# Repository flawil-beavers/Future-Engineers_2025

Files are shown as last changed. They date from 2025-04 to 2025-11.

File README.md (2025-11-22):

# Flawil Beavers

## Future-Engineers_2025

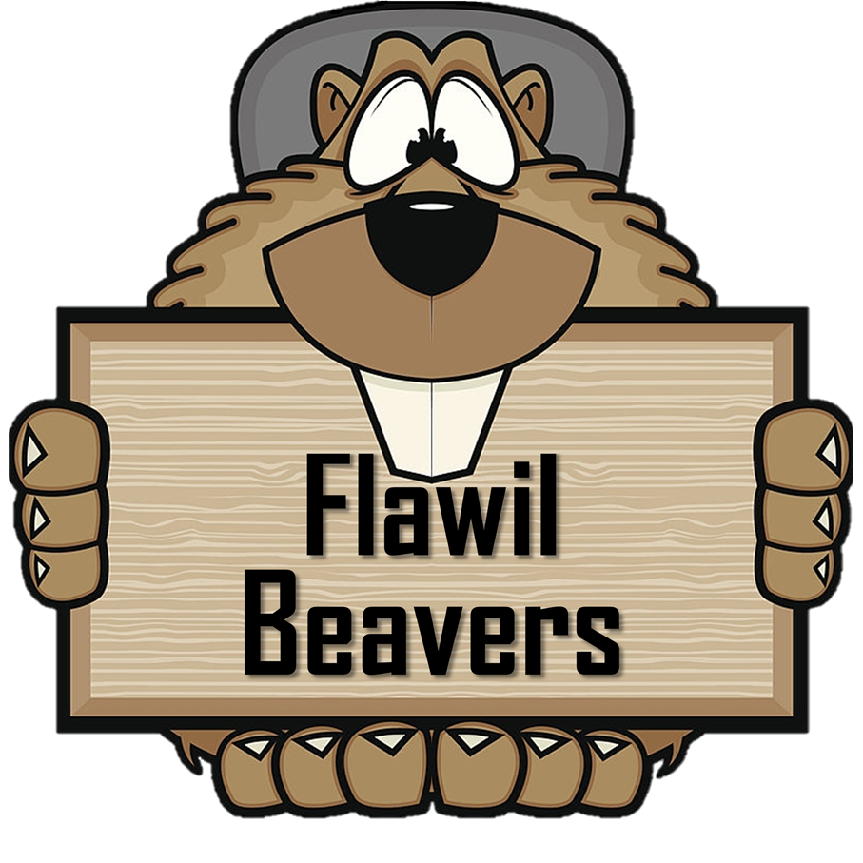
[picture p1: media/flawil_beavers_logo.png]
Flawil Beavers Logo


| Opening Challenge | Obstacle Challenge |
|---|---|
| Watch the Opening Race (https://youtu.be/OofLgNROook) | Watch the Obstacle Race (https://youtu.be/P_mGKfEbACU) |
|  |  |

**This is the GitHub repository for team Flawil Beavers for WRO 2025. You'll find our documentation in this README.**

---

## Contents

- [Introduction](#introduction)

- [Mobility Management](#mobility-management)
  - [Assembly Instructions](#assembly-instructions)
  - [Structural and Mechanical Design](#structural-and-mechanical-design)

- [Power and Sense Management](#power-and-sense-management)  
  - [Power Management](#power-management)  
  - [Sense Management](#sense-management)
  - [Wiring Diagram and Bill of Materials](#wiring-diagram-and-bill-of-materials)
    - [Wiring Diagram](#wiring-diagram)
    - [Bill of Materials](#bill-of-materials)

- [Obstacle Management](#obstacle-management)  
  - [Software Architecture](#software-architecture)  
  - [Opening Race](#opening-race)  
  - [Obstacle Race](#obstacle-race)  
    - [Colour Detection](#colour-detection)  
    - [Wall Following](#wall-following)
  - [Firmware Running on the Arduino](#firmware-running-on-the-arduino)  
    - [Overview of custom Firmware Operation](#overview-of-custom-firmware-operation)  
    - [System-Level Interaction Diagram](#system-level-interaction-diagram)

- [Own platform for Streams](#own-platform-for-streams)

- [Photos](#photos)  
- [Videos](#videos)

- [Enabling Reproducibility](#enabling-reproducibility)

- [Future Improvements](#future-improvements)

---

## Introduction

We, **Damian Hardegger** and **Philipp Kündig**, form the WRO team **Flawil Beavers**. Since 2019, we have been actively participating in the World Robot Olympiad, starting in the RoboMission category where we achieved several successful results. In 2024, we decided to take on a new challenge and moved into the Future Engineers category. There, we gained our first experience with autonomous driving and vehicle robotics — and even managed to win the Open Championships in Italy.

This documentation provides a complete technical overview of our Future Engineers project, including the mechanical design, electronics, software architecture, and our development process. The goal of this README is to offer a clear reference for judges, mentors, and other teams who may benefit from our approach, CAD files, wiring diagrams, and assembly instructions.

We believe in transparent engineering and hope that sharing our work contributes to the WRO community and inspires teams entering the Future Engineers category.

---

## Mobility Management

### Assembly Instructions

Below you’ll find a concise assembly guide covering all major build steps.

---

<details><summary><span style="font-size:1.4em; font-weight:700;">Step 1 – Preparations</span></summary>

Gather all required materials according to the [**Bill of Materials (BOM)**](#bill-of-materials) and print all necessary **[3D‑Printed‑Parts / CAD & STL](./CAD/Seperate%20Parts/)**.  
Use **M3 screws** and **M3nS/M3n nuts** for all mechanical components, and **M2 screws** with **M2n nuts** for electronic parts.

> ⚠️ **Note:**  
> For the **base plate** and **battery cover**, **magnets must be inserted after the printing process**.  

</details>

---

<details><summary><span style="font-size:1.4em; font-weight:700;">Step 2 – Base Plate and Drive Assembly</span></summary>

Take the printed **[base plate](./CAD/Seperate%20Parts/Base.3mf)** and begin by mounting the two **motors**.  
The **drive motor** is positioned in the center and secured with the [DC motor cover](./CAD/Seperate%20Parts/DC%20motor%20cover.3mf).  
Place a **coupling** between the motor shaft and the **LEGO axle** – we recommend a **metal coupling**, though [Shaft](./CAD/Seperate%20Parts/Shaft.3mf) can also be used.

Next, install the [Gearbox back](./CAD/Seperate%20Parts/Gearbox%20back.3mf) as well as the [Gearbox front](./CAD/Seperate%20Parts/Gerbox%20front.3mf) and [Gearbox front inset](./CAD/Seperate%20Parts/Gearbox%20front%20inset.3mf) on the base plate.  
Attach the **servo motor** using [Servo shaft](./CAD/Seperate%20Parts/Servo%20shaft.3mf) + [Servo shaft lego](./CAD/Seperate%20Parts/Servo%20shaft%20lego.3mf) and ensure all fasteners are tight.

Route the **motor cables to the side**, so they remain accessible later.  
Finally, verify that **all shafts are properly aligned and firmly fastened**.

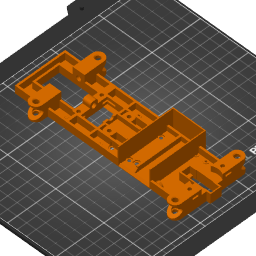
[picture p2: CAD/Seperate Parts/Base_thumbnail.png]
base plate
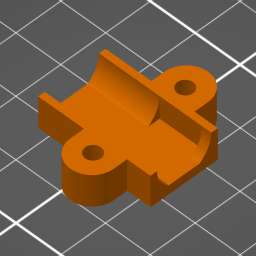
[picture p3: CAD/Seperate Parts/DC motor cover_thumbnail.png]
DC motor cover
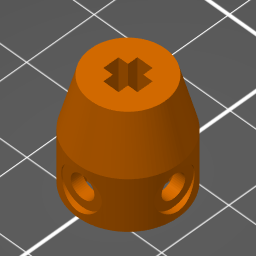
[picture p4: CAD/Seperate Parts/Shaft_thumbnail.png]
Shaft
|<br> **Base plate**|  <br> **DC motor cover** |  <br> **Shaft** |
|---|---|---|
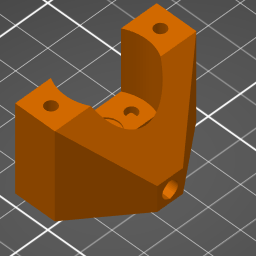
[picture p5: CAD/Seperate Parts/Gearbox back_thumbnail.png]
Gearbox back
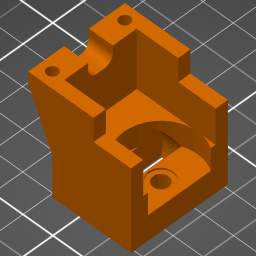
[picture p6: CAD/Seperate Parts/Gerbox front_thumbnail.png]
Gerbox front
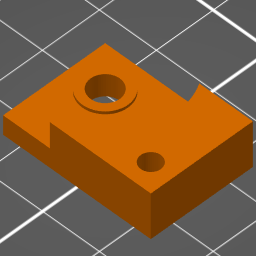
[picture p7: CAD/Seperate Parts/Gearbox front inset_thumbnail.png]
Gearbox front inset
| <br> **Gearbox back**|  <br> **Gerbox front** |  <br> **Gearbox front inset** |

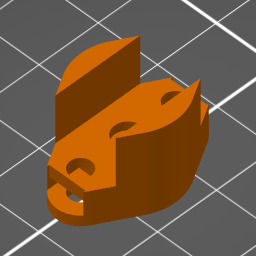
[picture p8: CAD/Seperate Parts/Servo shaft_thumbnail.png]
Servo shaft
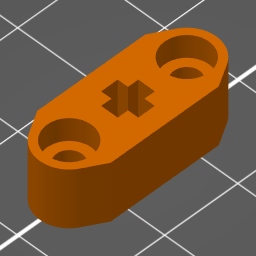
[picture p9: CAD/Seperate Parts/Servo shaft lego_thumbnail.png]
Servo shaft
 <br> **Servo shaft** | <br> **Servo shaft lego** |
|---|---|

</details>

---

<details><summary><span style="font-size:1.4em; font-weight:700;">Step 3 – LEGO Component Assembly</span></summary>

Attach the **LEGO components** to the 3D-printed parts as shown below.

**[LEGO Assembly](CAD/Lego_Chassis.io)**
<br>
<br>

<p align="center">
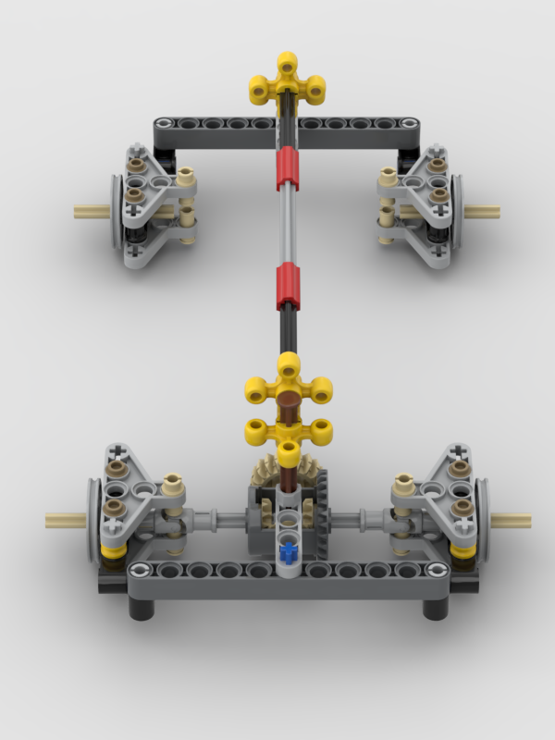
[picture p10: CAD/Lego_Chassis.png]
Lego Chassis
    
    <br>
    <strong>LEGO Chassis</strong>
</p>

Ensure all connections fit snugly and that no parts are misaligned.

</details>

---

<details><summary><span style="font-size:1.4em; font-weight:700;">Step 4 – Steering 
Axle</span></summary>

Check that you have installed both **gearboxes (step 2)** onto the base plate, then complete the **steering shaft assembly**.  
A **metal rod** is recommended; alternatively, a **16 cm LEGO steering bar** can be used.

These components secure all shafts in place and ensure stable **gear engagement**.  
Verify that all gears rotate smoothly and are properly meshed.

</details>

---

<details><summary><span style="font-size:1.4em; font-weight:700;">Step 5 – Computer Mounting Plate</span></summary>

Attach [Raspberry holder](./CAD/Seperate%20Parts/Rasbperry%20holder.3mf), the **mounting plate for the Raspberry Pi and the [cover top lower](./CAD/Seperate%20Parts/Cover%20top%20lower.3mf)**, to the supports installed in the previous step.  
Then, mount the [Camera mount](./CAD/Seperate%20Parts/Camera%20mount.3mf) on top of this plate as shown in the image.

**[Complete vehicle model](./CAD/Car%20v87.step)**

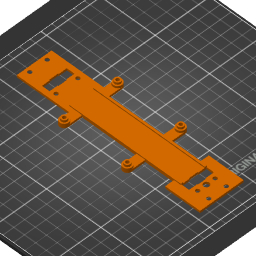
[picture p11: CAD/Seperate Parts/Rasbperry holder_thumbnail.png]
Raspberry holder
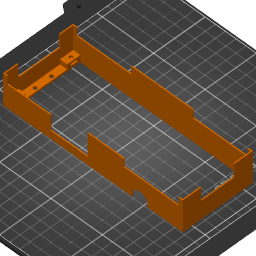
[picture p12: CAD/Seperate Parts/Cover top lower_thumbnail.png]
cover top lower
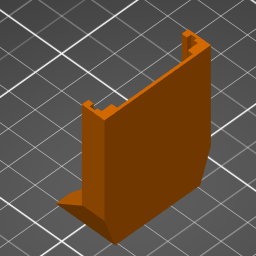
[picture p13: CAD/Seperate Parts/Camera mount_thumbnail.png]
Camera mount
|  <br> **Raspberry holder** |  <br> **cover top lower** |  <br> **Camera mount** |
|---|---|---|

<br>
Make sure the alignment is precise so that cables and connectors remain easily accessible.

</details>

---

<details><summary><span style="font-size:1.4em; font-weight:700;">Step 6 – Installing the Electronics</span></summary>

Flash the **micro SD card for the Raspberry Pi** and the **Arduino Nano** according to step 1 in **[software documentation](#enabling-reproducibility)**.

Mount the **Raspberry Pi** onto the upper plate.  
The **Arduino Nano** will be connected later and should remain **temporarily unattached** for now.

Carefully turn the robot upside down and install the remaining **electrical components** on the underside, following the reference picture.

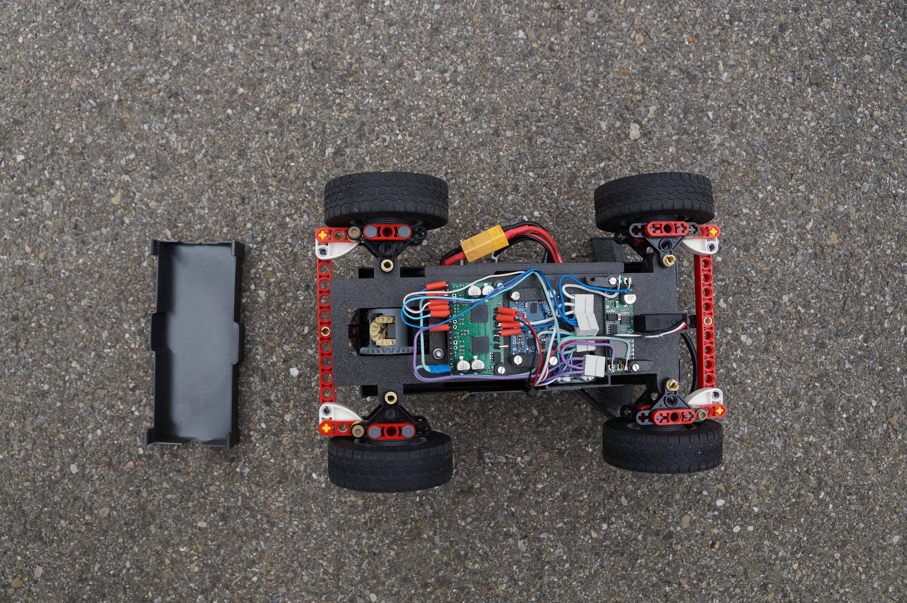
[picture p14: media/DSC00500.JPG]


Use the washers and fastening materials:

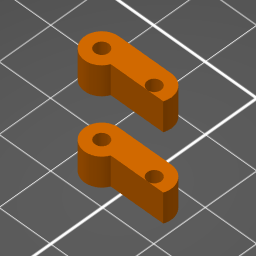
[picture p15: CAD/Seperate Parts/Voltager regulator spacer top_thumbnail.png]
Voltage regulator spacer top
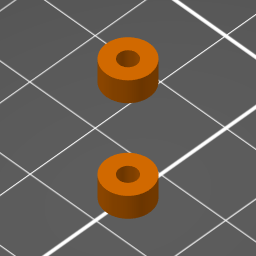
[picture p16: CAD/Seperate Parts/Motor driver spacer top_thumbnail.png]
Motor driver spacer top
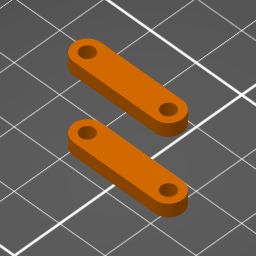
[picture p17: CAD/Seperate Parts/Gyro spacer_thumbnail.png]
Gyro spacer
|  <br> **[Voltage regulator](./CAD/Seperate%20Parts/Voltager%20regulator%20spacer%20top.3mf)**| <br> **[Motor driver](./CAD/Seperate%20Parts/Motor%20driver%20spacer%20top.3mf)** | <br> **[Gyro spacer](./CAD/Seperate%20Parts/Gyro%20spacer.3mf)**|
|---|---|---|

> 💡 **Tip:**  
> Use **nylon washers or plastic spacers** under PCBs to prevent short circuits.

</details>

---

<details><summary><span style="font-size:1.4em; font-weight:700;">Step 7 – Wiring</span></summary>

Follow the provided **[Wiring Diagram](#wiring-diagram)** to correctly interconnect all components.  
The **Arduino Nano** can temporarily remain on the top side for easy access.

Solder the wires of the power components on the underside and use **connectors** where possible to simplify maintenance.  
For the main power supply, **WAGO terminals** can be placed in the front interior compartment of the robot.

> ⚠️ **Warning:**  
> Double-check **all GND and power connections**.  
> Incorrect wiring may damage components or even cause **short circuits and fire hazards**.

</details>

---

<details><summary><span style="font-size:1.4em; font-weight:700;">Step 8 – Enclosure Assembly</span></summary>

Place [Bottom cover](./CAD/Seperate%20Parts/Bottom%20cover.3mf) over the wiring from underneath – it should **snap into place securely**.  
Then, flip the robot back upright and prepare the [top cover](./CAD/Seperate%20Parts/Cover%20top%20upper.3mf).

Mount the **toggle switches** and the **status LED** as shown, and connect them directly to the Arduino.

Before fully closing the housing:

1. Connect the **camera module** and route the ribbon cable through the opening.  
2. Link the **Arduino Nano** to the **Raspberry Pi** using a **USB-A to Micro-USB cable**.  
3. Once completed, install and fasten the housing completely.

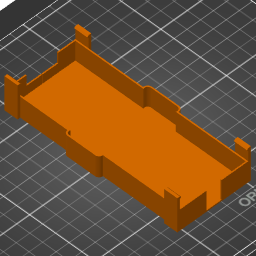
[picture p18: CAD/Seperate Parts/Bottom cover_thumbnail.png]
Bottom cover
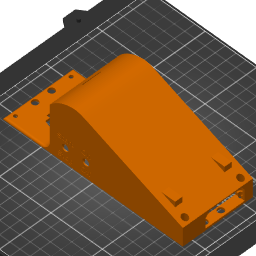
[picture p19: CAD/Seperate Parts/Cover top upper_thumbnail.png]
top cover
|  <br> **Bottom cover** |  <br> **Top cover** |
|---|---|

</details>

---

<details><summary><span style="font-size:1.4em; font-weight:700;">Step 9 – Hardware Finalization</span></summary>

Mount the **camera** at the front of the robot.  
Carefully attach the **lens**, making sure it is free of dust and properly focused.  
Tighten it fully to prevent image blur caused by vibration.

To finish:

- Install the [rear spoiler](./CAD/Seperate%20Parts/spoiler_full_2.3mf) (for that extra aerodynamic performance 😎).
- Don't forget to install the [Battery holder](./CAD/Seperate%20Parts/Battery%20holder.3mf).
- Attach the **wheels**.

Your robot’s **hardware assembly** is now complete and ready for operation.

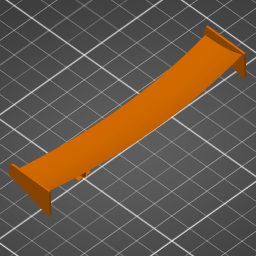
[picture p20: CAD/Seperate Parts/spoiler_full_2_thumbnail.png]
Rear spoiler
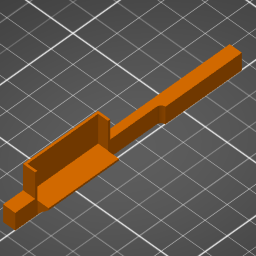
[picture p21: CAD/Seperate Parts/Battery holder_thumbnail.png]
Battery holder
|  <br> **Rear spoiler 😎** |  <br> **Battery holder** |
|---|---|

</details>

---

<details><summary><span style="font-size:1.4em; font-weight:700;">Step 10 – Software Installation and Setup</span></summary>

Carefully read through the **[software documentation](#enabling-reproducibility)** and install all required software packages on the **Raspberry Pi** and **Arduino Nano**.  
Upload the corresponding **firmware, scripts, and configuration files** as described in the software section.

> **Congratulations!**  
> Your robot is now fully assembled and ready for its first run.  
> Enjoy driving, experimenting, and improving your creation!

</details>

---

<!-- Mobility management discussion should cover how the vehicle movements are managed. What motors are selected, how they are selected and implemented.
A brief discussion regarding the vehicle chassis design /selection can be provided as well as the mounting of all components to the vehicle chassis/structure. The discussion may include engineering principles such as speed, torque, power etc. usage. Building or assembly instructions can be provided together with 3D CAD files to 3D print parts. -->

### Structural and Mechanical Design

The robot is constructed almost entirely from 3D-printed components, with the exception of axles, wheels, and gears made from Lego parts. Lego components were chosen for their flexibility and ease of replacement. To improve precision and durability, we upgraded one axle and one coupling from plastic to metal, enhancing mechanical reliability under repetitive use.

All electronic components are embedded directly into the 3D-printed structure. The robot employs a double Ackerman steering mechanism on both axles, allowing precise control and tight turning. A differential is integrated into the front axle to evenly distribute torque between the front wheels, improving stability and efficiency during motion.

A complete overview of the 3D-printed parts and how they fit together can be seen in our Fusion 360 model:

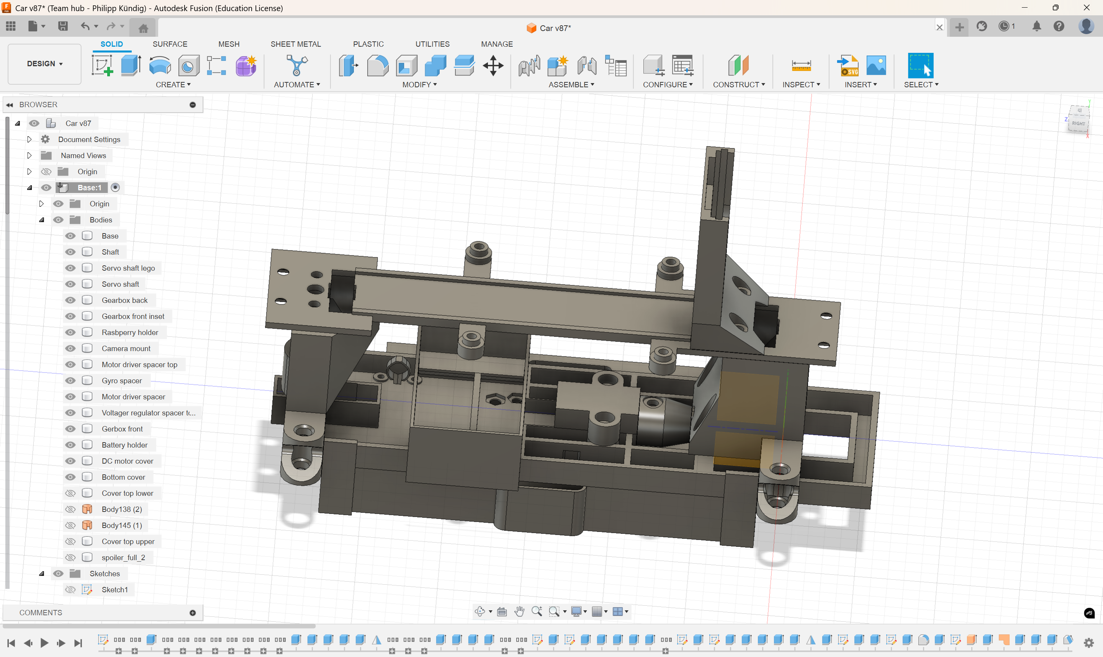
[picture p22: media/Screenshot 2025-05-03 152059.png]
3D object 1

*Screenshot of the robot model in Fusion 360 showing all 3D components fully assembled.*

This model illustrates how the parts are positioned within the chassis, giving a clear view of the mechanical layout before printing.

**Motors and Actuation:**

- A 12 V, 220 rpm DC motor with a 150:1 gear ratio drives the robot. Despite its moderate speed, the motor provides a high torque of 1.8 kg·cm at 0.75 A quiescent current, ensuring smooth acceleration and precise movement.
- The motor is mounted as low as possible to minimize the center of gravity, improving stability.
- Steering is achieved with an RC servo motor with 1.9 kg·cm holding torque, connected via a 3D-printed coupling and Lego gears. To allow the front and rear axles to steer independently without direct connection, the servo linkage is routed above the motor, which is positioned beneath the linkage for compactness and accessibility.

Before printing, the 3D-printed parts are prepared in PrusaSlicer to optimize orientation, supports, and slicing parameters:

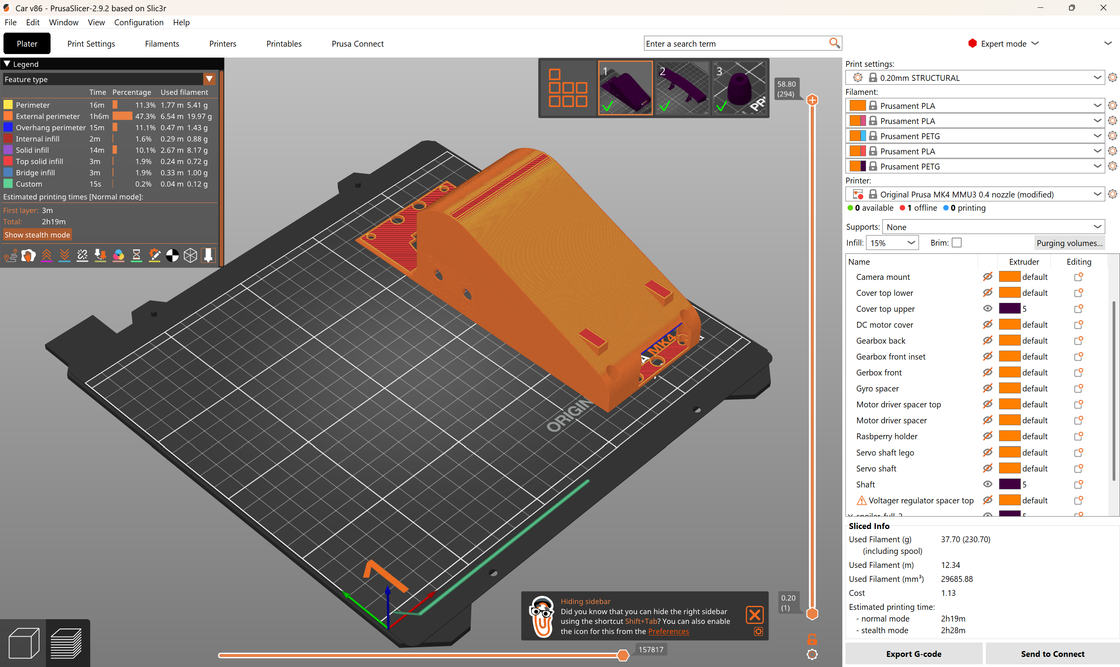
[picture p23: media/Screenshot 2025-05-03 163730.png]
3D object 2

*Screenshot of the car cover in PrusaSlicer showing the cover sliced and ready for 3D printing.*

This step ensures that the printed components match the design exactly and can be easily assembled with the Lego and metal parts.

**Component Mounting and Assembly:**

- Additional 3D-printed parts were designed for the camera mount, electronics plates, and battery holder. The camera mount allows easy insertion from above, while other electronics are mounted on plates above or below the chassis depending on available space.
- All components are secured using standard M3 or M2 hardware, with nuts pressed into the 3D prints post-printing, eliminating the need for support structures and ensuring strong, reliable connections. Square or hexagonal nuts were selected based on accessibility.
- The battery is mounted low and held by a magnetic mount, allowing quick replacement while maintaining a low center of gravity.

**Design Improvements:**

- Metal axles and couplings reduce wear and improve steering precision compared to purely plastic parts.
- Embedded pockets for the nuts reduce assembly complexity, precision required and increase durability.
- Placement of the motor and servo for optimized torque distribution and stability demonstrates thoughtful engineering beyond simple duplication.
- The modular design of the 3D-printed parts and use of standard hardware allows others to replicate the robot exactly while also implementing these improvements.

---

<!-- Power and Sense management discussion should cover the power source for the vehicle as well as the sensors required to provide the vehicle with information to negotiate the different challenges. The discussion can include the reasons for selecting various sensors and how they are being used on the vehicle together with power consumption. The discussion could include a wiring diagram with BOM for the vehicle that includes all aspects of professional wiring diagrams. -->

## Power and Sense Management

### Power Management

The robot is powered by a standard 4S LiPo battery (14.8 V), chosen for its flexibility, commercial availability, and high energy density. The battery supplies the drive motor directly via the MC33926 Motor Driver Carrier, while a DC-DC step-down converter provides a stable 5 V supply for the Raspberry Pi 4B and Arduino Nano.

This separation of power lines improves system reliability and component safety: the Raspberry Pi and servo motors are not affected by transient loads on the drive motor, and no components need to be rated for unnecessarily high combined currents. The Raspberry Pi draws up to 1.2 A, the servo can require 0.6 A when stalled, and the DC motor consumes 0.75 A under load. The selected step-down converter safely supports these demands.

Motor control is handled via the Arduino Nano, which receives commands from the Raspberry Pi. The Motor Controller enables 12 V motor operation using just three control pins from the 5 V Arduino: two for direction and one for PWM speed control, allowing precise and efficient driving while isolating the high-voltage motor system from the low-voltage logic.

The battery is mounted as low as possible in the chassis to maintain a low center of gravity, improving stability during acceleration and turns. A magnetic mount allows easy replacement or charging of the battery.

---

### Sense Management

Based on last year’s experiments with multiple sensors, we determined that a single camera is sufficient for navigation, provided it has a wide field of view. We therefore selected the Raspberry Pi HQ camera with a 120° lens, giving the robot a detailed, wide-angle view of its environment. The camera is mounted 100 mm above the floor, ensuring that image processing focuses on the lower half of the environment for accurate wall and obstacle detection.

A gyroscope has been added to supplement visual navigation, enabling more precise turns and improved straight-line stability. Power for the camera is supplied directly from the Raspberry Pi, while the Raspberry Pi itself receives regulated 5 V from the DC-DC converter.

Compared to the previous iteration, ultrasonic sensors were removed, simplifying the design and reducing power consumption. This shows a clear improvement in both simplicity and efficiency without sacrificing performance.

---

### Wiring Diagram and Bill of Materials

The [wiring diagram](#wiring-diagram) provides a professional overview of all connections, showing how power, sensors, and control signals interact. The [Bill of Materials (BOM)](#bill-of-materials) lists all components with amounts, sources, and prices, including self-made 3D-printed parts and LEGO components. Combined with the wiring diagram and assembly instructions, this allows anyone to replicate the system exactly, while also benefiting from the improvements implemented this year.

#### Wiring Diagram

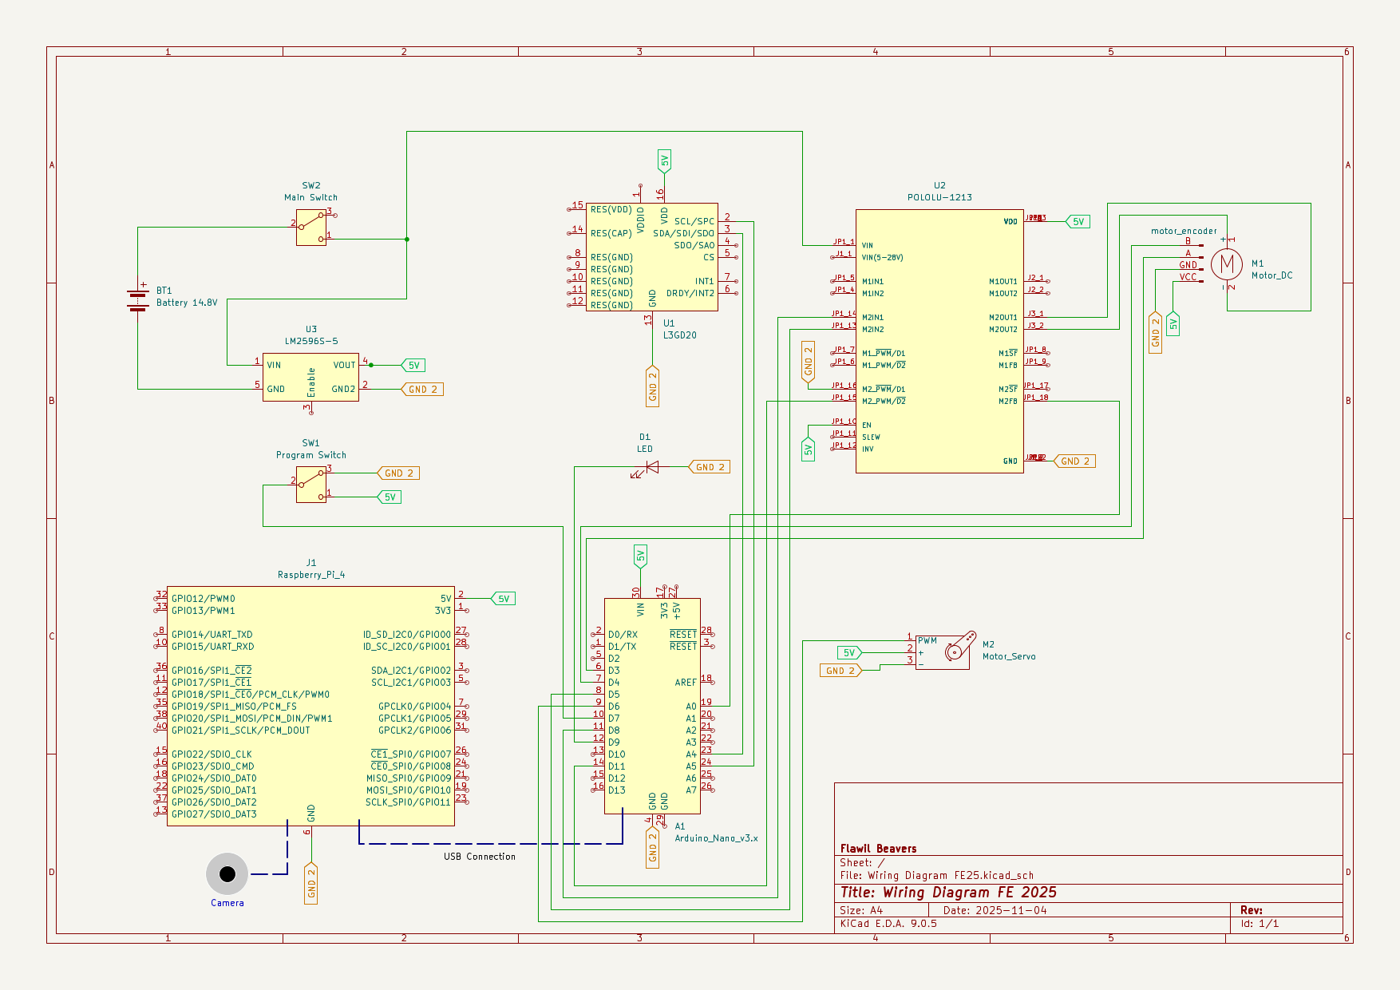
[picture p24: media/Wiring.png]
Wiring Diagram


---

#### Bill of Materials

| **Amount** | **Product** | **Price (CHF)** | **Source** |
|---|---|---|---|
| 1 | Raspberry Pi M12 HQ Camera | 45.34 |[Google](https://www.raspberrypi.com/documentation/accessories/camera.html)|
| 1 | EDATEC 12MP 3.2mm M12 Raspberry | 28.84 |[Google](https://edatec.cn/docs/assets/m12-lens/170320-12/ED-LENS-M12-170320-12-datasheet-en.pdf)|
| 1 | Raspberry Pi 4 Model B 8GB | 79.00 |[Google](https://datasheets.raspberrypi.com/rpi4/raspberry-pi-4-datasheet.pdf)|
| 1 | Arduino Nano: Multifunktional Board ATmega328 16Mhz, Mini-USB | 19.95 |[Google](https://store.arduino.cc/products/arduino-nano)|
| 1 | Tattu LiPo-Akku 14.8V 850mAh 95C 4S1P RL | 14.00 |[Google](https://swissbatt24.ch/geraetebatterien/rc-drohnen/drohnen/4060/tattu-850mah-14-8v-4s1p-r-line-95c-lipo-akkupack-mit-xt30-stecker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)|
| 1 | Pololu Dual MC33926 Motor Driver Carrier | 52.95 |[Google](https://www.pololu.com/product/1213)|
| 1 | Amewi 0902MG Micro Servo | 14.40 |[Google](https://www.digitec.ch/de/s1/product/amewi-digital-amx-racing-0902mg-rc-servo-12872149)|
| 1 | IMU 9-Axis L3GD20, LSM303D [H07] | 6.10 |[Google](https://www.adafruit.com/product/1714)|
| 1 | 150:1 Micro Metal Gearmotor HPCB 12V with 12 CPR Encoder, Side Connector  | 29.64 |[Google](https://www.pololu.com/product/3042)|
| 2 | Changeover switch | 4.00 ||
| 1 | USB-A to USB-micro cable 15cm | 7.80 ||
| 1 | LED | 0.50 ||
| ~20 | M3 Screws and Nuts | 2.00 ||
| ~10 | M2 Screws and Nuts | 1.00 ||
| ~300g | 3D Printing Filament | 5.00 ||
| ~20 | Jumper Cables | 4.00 ||
| 8 | electrical connectors | 3.00 ||
| 1 | metal drive shaft | selfmade ||
| 1 | motor shaft coupling | selfmade ||
| A Few | LEGO Technic Bricks | - ||
| 4 | LEGO Technic Wheels | - ||
| **TOTAL**  | | **317.52** |

All 3D-printed parts can be printed without supports at 0.2 mm layer height using PET-G or nGen (PLA is also acceptable). Files are available in the 3D‑Printed‑Parts](./CAD/Seperate%20Parts/) Folder, and LEGO chassis instructions are provided in the [Lego_Chassis.io](CAD/Lego_Chassis.io) file.

---

## Obstacle Management

<!-- Obstacle management discussion should include the strategy for the vehicle to negotiate the obstacle course for all the challenges. This could include flow diagrams, pseudo code and source code with detailed comments. -->

### Software Architecture

Our main program runs on python asynchronously. Thanks to the `asyncio` library, we can run multiple loops at the same time. The main components of our program are the image processing loop, the Arduino communication loop, the main program loop and the webserver loop (if not in headless mode). The following flowchart illustrates how these components interact:

```mermaid
flowchart TD
    main("main()")
    main --> cycle("cycle_loop()")
    main --> arduino("arduino_communication_loop()")
    main --> main_program("main_program()")
    main --> |if not headless| webserver("run_webserver()")
    webserver --> web["starts webserver and serves streams"]
```

To coordinate between the asynchronous loops, the system uses two main classes:

- `Car`, which describes the instantaneous state of the vehicle, and

- `SharedState`, which holds all shared data, flags, and vision results.

```mermaid
classDiagram
    direction LR
    class Car {
        +Car State: angle, distance, speed, steering
        +Flags: paused, stalled
    }
    class SharedState {
        +Streams
        +Vision Results
        +State Flags
        +Control Parameters
    }
```

The `run_webserver()` function starts a web server that serves camera streams and robot telemetry. This loop runs only if the program is not in headless mode.

The `cycle_loop()` handles image acquisition and processing. It continuously captures frames from the camera, applies filtering (extracting red, green and pink stream using hsv and then [Thresholding](https://docs.opencv.org/4.x/d7/d4d/tutorial_py_thresholding.html)), and detects edges using [Canny Edge detection](https://docs.opencv.org/4.x/da/d22/tutorial_py_canny.html). If headless mode is off, the processed frames are visualized in real time.

```mermaid
flowchart LR
    cycle("cycle_loop()")
    cycle --> process["take new frame"]
    process --> filter["filter the image"]
    filter --> edges["detect edges"]
    edges --> |if not headless| viz["visualize"]
    edges --> |if headless| process
    viz --> process
```

The `arduino_communication_loop()` manages low-level communication with the Arduino. It waits for the Arduino to connect via serial, sends speed and steering commands, and receives angle and distance readings. The loop continuously updates the `Car` class with the latest sensor data.

```mermaid
flowchart LR
    arduino("arduino_communication_loop()")
    arduino --> waitcon["wait for connection"]
    waitcon --> arduino_connection["send speed and steering"]
    arduino_connection --> arduino_receive["receive angle and distance"]
    arduino_receive --> arduino_connection
```

To communicate with the Arduino, we use the `pyserial` library. The Arduino is programmed to receive speed and steering commands via serial communication and send back angle and distance measurements. The communication protocol is simple: the Raspberry Pi sends a formatted string containing speed and steering values, and the Arduino responds with a formatted string containing angle and distance readings.

The `main_program()` controls the high-level challenge logic. It waits for the Arduino to connect and for the start switch to be enabled. Once started, it decides whether to execute open challenge logic or obstacle challenge logic based on the challenge type given as flag.

```mermaid
flowchart LR
    main_program("main_program()")
    main_program --> wait["wait for Arduino to connect"]
    wait --> wait2["wait for Arduino to send switch enable start"]
    wait2 --> mainprog["start the main program"]
    mainprog --> pillar{Pillar round?}
    pillar --> |yes| pillary(open challenge logic)
    pillar --> |no| pillarn(obstacle challenge logic)
```

### Opening Race

```mermaid
flowchart LR
    open("open challenge logic") --> side["round detection"]
    side --> pd["pd middle"]
    pd --> |orange/blue line| inc["rounds++"]
    inc --> line["turn 90°"]
    line --> decision{"rounds < 12"}
    decision --> |True| pd
    decision --> |False| stop["PD middle and stop"]
```

We begin by determining the `round direction`. First, we crop the top half of the image and filter out all black pixels using OpenCV's [`cv2.inRange`](https://docs.opencv.org/4.x/da/d97/tutorial_threshold_inRange.html) function. On this Boolean map of black pixels, we detect edges using [`cv2.Canny`](https://docs.opencv.org/4.x/da/d22/tutorial_py_canny.html). By applying `np.argmax`, we find the heights of the walls in pixels at each x-coordinate in the image. The discrete differences between these heights are calculated using `np.diff`, raised to the fourth power, and summed up. This helps us identify the jump in wall height when the inner wall first appears.

For driving, we employ a PD-Controller in `pd_middle`. The input is derived from the black portion of a region-of-interest extracted from the outer edges of the black-and-white Boolean image. This is compared to a pre-calibrated fixed portion. We follow only the outer wall to avoid collisions with the inner walls, especially if their gap distance is randomized to be small.

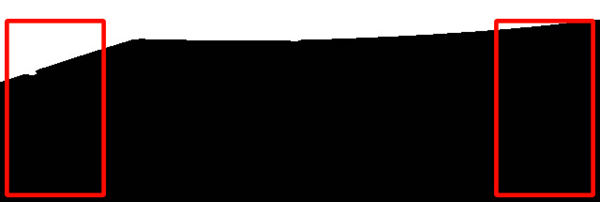
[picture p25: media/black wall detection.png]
Wall Detection


The red outlines show the region of interest (ROI) used for wall detection.

Using a small ROI in the center of the camera feed (green rectangle), we detect the blue and orange lines on the game mat. The color image is converted to HSV for this purpose. Upon encountering such a line, depending on its color, we initiate a turn and decrement the remaining corners counter, allowing us to accurately stop at the end of the round.

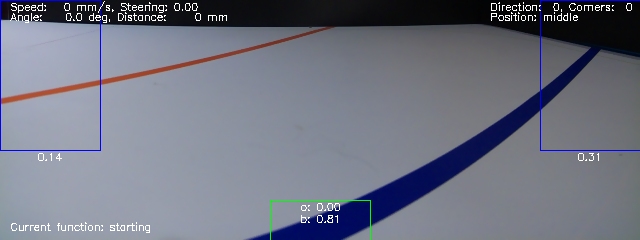
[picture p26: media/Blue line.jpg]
Blue line


The decimal numbers in the green rectangle show the percentage of orange and blue pixels.

---

### Obstacle Race

```mermaid
flowchart TD
    open("Obstacle challenge logic") --> side["Determine round direction"]
    side --> unpark["Unpark"]
    unpark --> photo["Take Photo"]
    photo --> route["Avoid Obstacles and follow Wall"]
    route --> rounds{"Rounds?"}
    rounds --> |"< 5"| dw["Drive to Wall"]
    dw --> back["Backward Turn"]
    back --> photo2["Take Photo"]
    photo2 --> double1["Double Turn"]
    double1 --> fol1["Follow outer Wall 1"]
    double1 --> fol2["Follow inner Wall 1"]
    fol3["Follow outer Wall 2"]
    fol4["Follow inner Wall 2"]
    fol1 & fol2 --> fol3 & fol4
    fol3 & fol4 --> double2["Double Turn / Predefined Route"]
    double2 --> increment["Rounds ++"]
    increment --> rounds

    rounds --> |"< 13"| predefroute["Predefined Route"]
    predefroute --> fol1 & fol2

    rounds --> |"= 13"| drpark["Drive to Parking Lot"]
    drpark --> park["Parallel Parking"]
```

First we determine the `round direction` based on how much black we see on each side in the blue ROI.

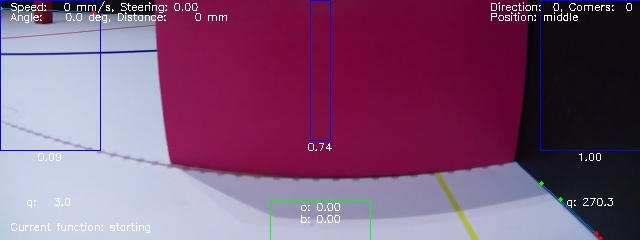
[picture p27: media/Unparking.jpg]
Unparking


Then we `unpark` by performing a turning sequence. Before starting to drive the rounds we evaluate the current image for pillars and decide whether we have to avoid a pillar. The robot continues driving until it is near to the wall. Then it takes a backward turn to realign itself and starts driving again. After taking another picture we evaluate the pillars again.

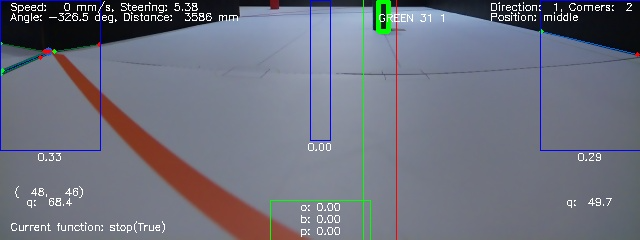
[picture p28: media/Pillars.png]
Pillar detection


If there are pillars, it performs a double turn to avoid the pillars and then continues following the correct wall. If there are two pillars, the robot will change side in the middle of the section. After another double turn we increment the rounds counter

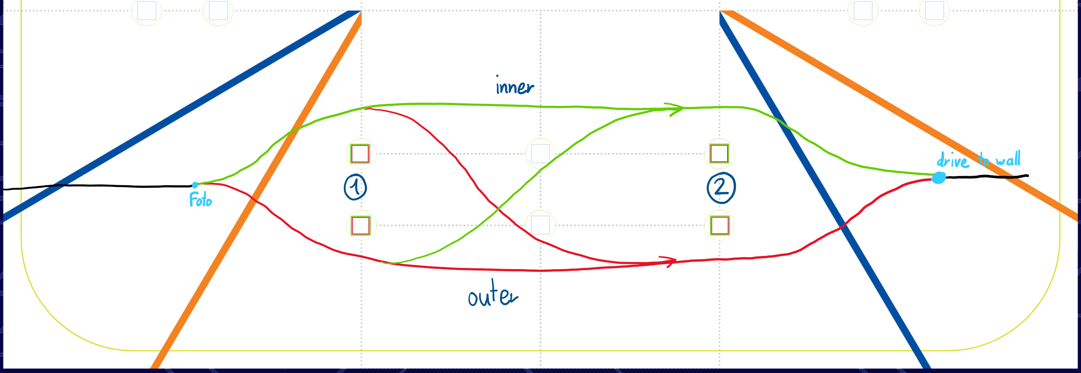
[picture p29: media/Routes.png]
Routes around Pillars


After completing 5 rounds, the robot follows predefined routes for each round. After completing 13 rounds, the robot drives to the parking lot and performs parallel parking.

#### Colour Detection

In addition to extracting a black-and-white image, we convert the cropped color image to HSV. This conversion allows us to more easily and robustly extract red and green pixels. We then use [`cv2.Canny`](https://docs.opencv.org/4.x/da/d22/tutorial_py_canny.html) and [`cv2.findContours`](https://docs.opencv.org/3.4/d4/d73/tutorial_py_contours_begin.html) to search for contours in this image. The centroids of the contours are extracted and stored along with their width and height.

When handling the HSV color space, special care is needed for colors near the red hue due to the wrap-around effect. The hue value for red is around 0° and 360°, meaning it wraps around the HSV color wheel. To accurately detect red, we create two separate masks: one for the lower range (e.g., 0° to 10°) and another for the upper range (e.g., 350° to 360°). These masks are then combined to form a single mask that accurately captures all red hues. This approach ensures that all shades of red are detected, avoiding issues caused by the hue value wrapping around the color wheel.

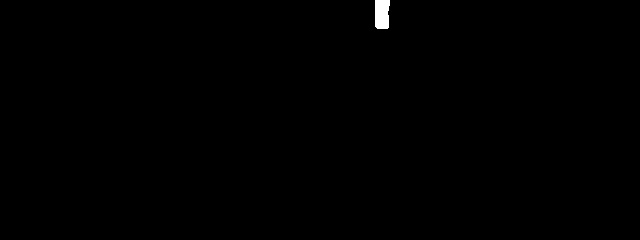
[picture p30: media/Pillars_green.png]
Green mask


In the image above you can see the robot detecting the green pillars with the mask. It's the mask from the other [visualization](media/Pillars.png). After processing the image, the program returns a list of found pillars, sorted by their distance to the robot. The robot then drives towards the closest pillar, until it is close enough to the pillar to avoid it. The robot then drives around the pillar and continues to the next one. You can also see the center ROI used for detecting turn marking lines.

#### Wall Following

We follow the walls using the point-slope-form of the border line between the black wall and the white mat. This is again extracted using [`cv2.Canny`](https://docs.opencv.org/4.x/da/d22/tutorial_py_canny.html). We use the PD controller to keep the y-intercept of the lines on a constant height. By including the gyro values quadratically in the steering calculation, we can further stabilise the driving so that the robot does not take a U-turn. Furthermore there is a corner detection algorithm that switches the wall following to gyro corrected driving, when passing the end of the walls. In the following image you can see the corner being detected on the left ROI where two red ends of detected edges meet.

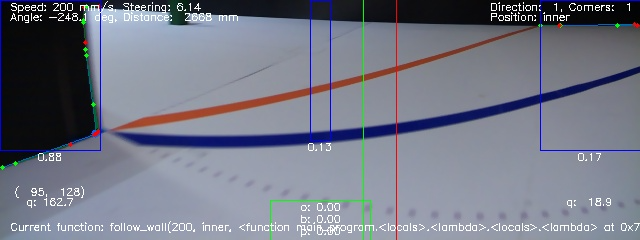
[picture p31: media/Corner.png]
Corner


---

### Firmware Running on the Arduino

The Arduino interfaces directly with the DC motor, servo, gyro sensor, switches, and status LED. Its primary role is to exchange sensor data and control commands between these peripherals and the Raspberry Pi. To support this, we implemented a custom firmware tailored to the robot’s needs.

The high-level program flow is illustrated below:

```mermaid
flowchart TD
    program_start("Arduino start") --> ISR
    program_start --> main["main_loop()"]

    main --> readgyro["Read gyro + integrate angle"]
    readgyro --> readserial["Handle serial I/O"]
    readserial --> controlmotors["Control motors
     (PID + steering)"]
    controlmotors --> main

subgraph ISR["Interrupt Service Routines"]
    I1("ISR: Encoder tick")
    I2("ISR: Switch toggle") --> EN["Toggle enable state"]
end

EN -. sends .-> Ser("Report state change over serial")
I1 -. updates .-> I1b("Update encoder distance")
```

#### Overview of custom Firmware Operation

At startup, the Arduino initializes the serial connection, configures motor and servo pins, and attaches interrupt handlers for the encoder signals and the enable switch.
When the enable switch changes state, the corresponding interrupt fires and the new state is immediately sent to the Raspberry Pi.

The **main loop** performs four continuous tasks:

1. **Gyro reading and angle integration**
   The Arduino reads the angular velocity from the gyro and integrates it to estimate the robot’s heading. A custom temperature compensation model is applied to increase accuracy.

2. **Serial communication**
   The current heading and encoder-based distance are sent to the Raspberry Pi.
   At the same time, the Arduino receives speed and steering commands from the Pi.

3. **Motor and steering control**

   - The servo angle is set directly.
   - The DC motor speed is regulated using a PID controller, which keeps the velocity stable even under load.
     The PID feedback signal is derived from the encoder distance change over time.

4. **Safety and diagnostics**
   The firmware monitors conditions that indicate mechanical issues:

   - **Stall detection:**
     If the encoder shows almost no movement while the PID demands maximum PWM, the robot is considered stalled.
     In this case, the motor is shut down to prevent overheating, and an error message is sent to the Raspberry Pi.
   - **Current sensing:**
     The MC33926 motor driver provides analog current feedback.
     Although this feature is not highly reliable for small motors, it acts as an additional emergency-level safeguard.

Together, these systems ensure that the Arduino can reliably control the robot’s drivetrain, report accurate sensor data, and react quickly to unsafe conditions.

#### System-Level Interaction Diagram

The diagram below shows how the Raspberry Pi loops interact with the Arduino firmware. The Pi runs asynchronous loops for image processing, main logic, Arduino communication, and optionally a webserver.

**SharedState** and **Car** coordinate sensor readings, vision results, and control flags. The Arduino handles low-level motor/servo control, reads gyro and encoder data, executes PID control, and sends feedback over serial. Commands and feedback form a closed control loop between the Pi and Arduino.

This diagram summarizes how high-level logic, vision, and low-level control work together to navigate obstacles.

```mermaid
flowchart TD
    subgraph RaspberryPi
        A1["main_program()"]
        A2["cycle_loop()"]
        A3["arduino_communication_loop()"]
        A4["run_webserver()"]
    end

    subgraph Shared["SharedState / Car"]
        S1["Sensor Data & Flags"]
        S2["Vision Results"]
    end

    subgraph Arduino
        B1["Main Loop: PID, Motors"]
        B2["Gyro + Encoder Readings"]
    end

    A1 --> S1
    A2 --> S2
    A3 --> S1
    S1 --> A1
    S2 --> A1
    A3 --> B1
    B2 --> A3
    S1 --> A3
    S2 --> A4
```

---

## Own platform for Streams

We created our own HTML file to display the camera image. This is used to send three streams constantly to our connected device in preparation mode. During the competition, we disable the communication so that the Raspberry Pi can use all its computational resources for the run. Using the streams limits the performance of the robot as much time is spent on sending the streams. Therefore, we disable it.
With our HTML file, we can also read out the color values of the environment and send these changes directly to the robot. We can change the different streams via websocket and thus display images with different filters on them.

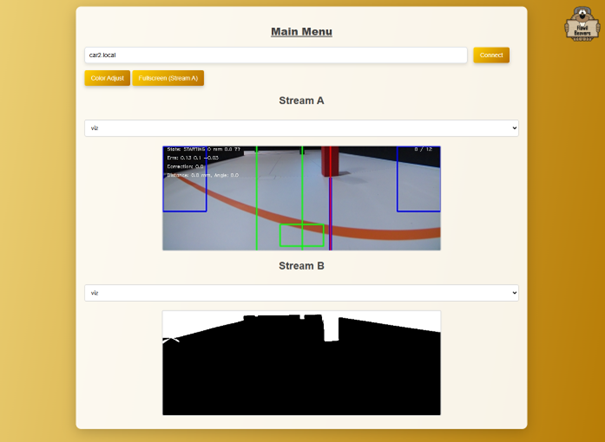
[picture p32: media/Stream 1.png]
Stream 1
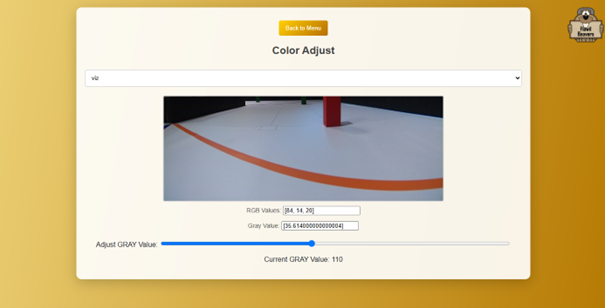
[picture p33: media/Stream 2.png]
Stream 2
|  |  |
|---|---|

---

<!-- Pictures of the team and robot must be provided. The pictures of the robot must cover all sides of the robot, must be clear, in focus and show aspects of the mobility, power and sense, and obstacle management. Reference in the discussion sections 1, 2 and 3 can be made to these pictures. Team photo is necessary for judges to relate and identify the team during the local and international competitions. -->

## Photos

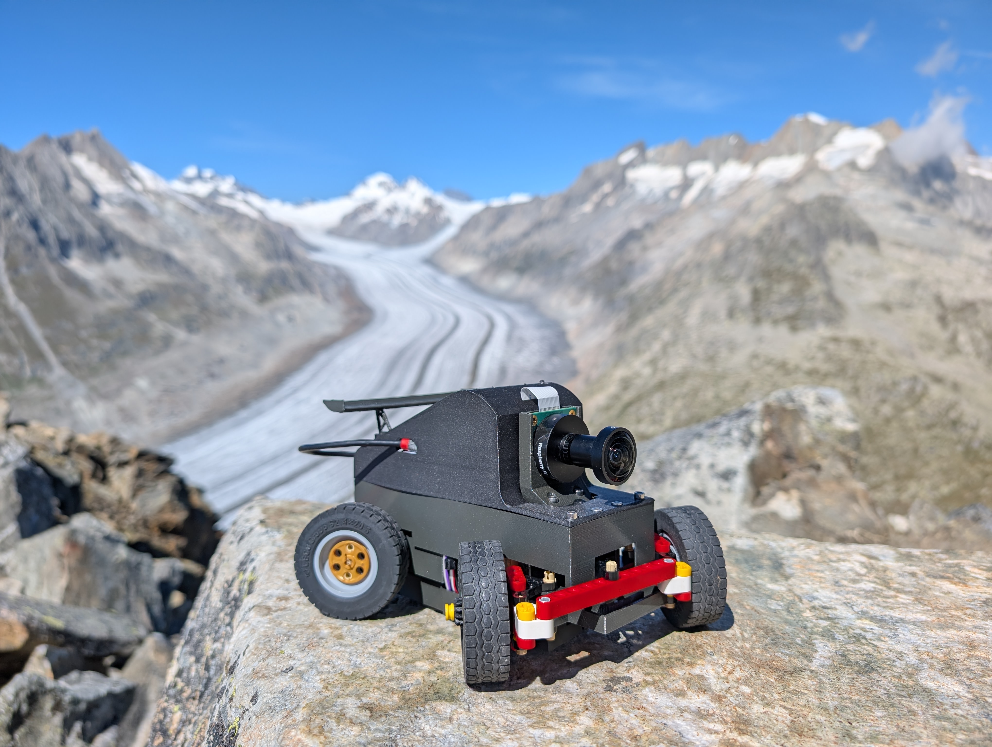
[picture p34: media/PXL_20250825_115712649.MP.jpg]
Our Robot Car enjoying the View on the Aletsch Glacier


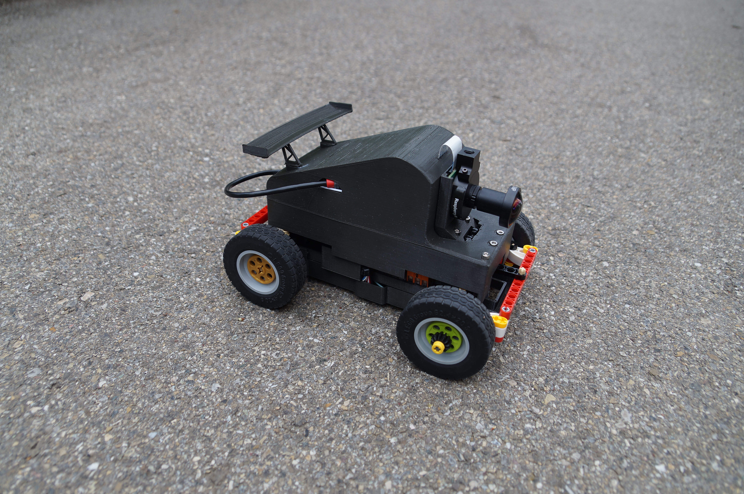
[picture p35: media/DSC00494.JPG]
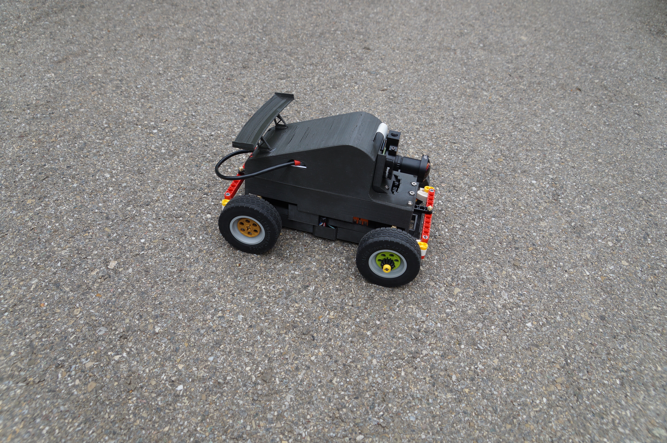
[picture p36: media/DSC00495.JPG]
|  |  |
|---|---|
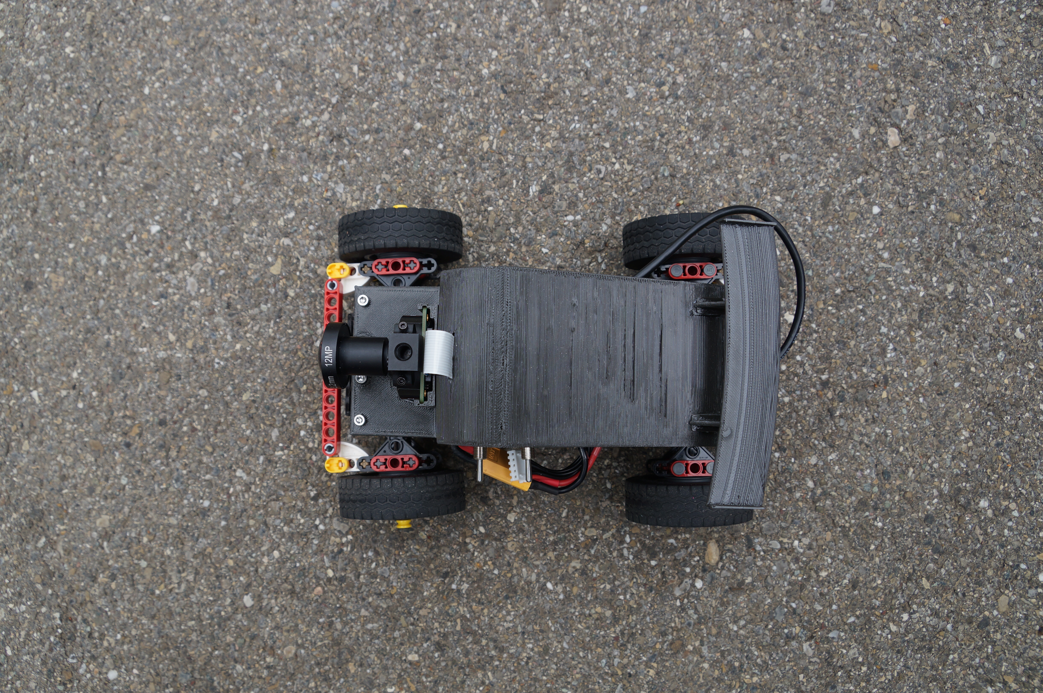
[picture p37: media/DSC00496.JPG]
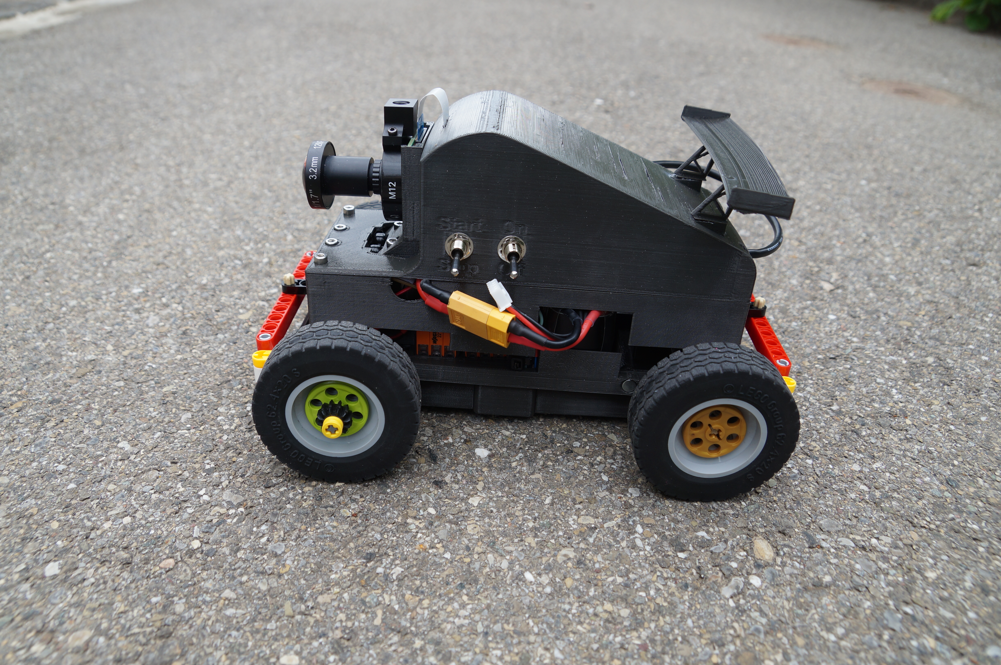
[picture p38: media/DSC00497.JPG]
|  |  |
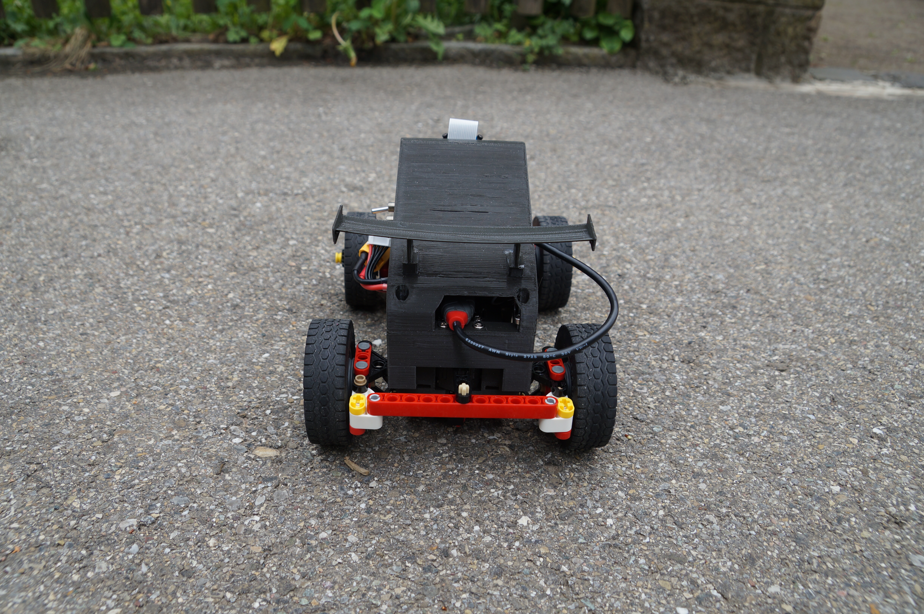
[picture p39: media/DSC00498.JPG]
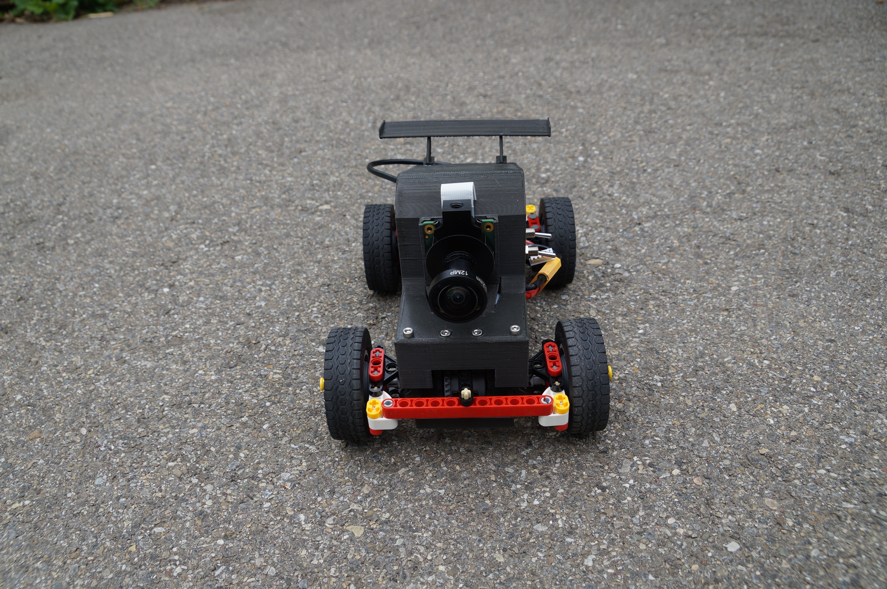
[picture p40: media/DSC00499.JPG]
|  |  |
|  |  |
|  |  |

Teamphoto Flawil Beavers 2025

| Team | Team|
|---|---|

**The national menu of Switzerland is fondue. While usually fondue is made from cheese, the team is enjoying a robot fondue 😎🤪**

<!-- The performance videos must demonstrate the performance of the vehicle from start to finish for each challenge. The videos could include an overlay of commentary, titles or animations. The video could also include aspects of section 1, 2 or 3 -->

## Videos

<!-- https://michaelcurrin.github.io/badge-generator/#/generic -->





---

## Enabling Reproducibility

To enable the reproduction of our robot, we provide the following installation instructions:

1. Install Raspberry Pi OS on your Raspberry Pi using the [official guide](https://www.raspberrypi.org/documentation/installation/installing-images/README.md) While the os is installing, you can flash the Arduino code to the Arduino Nano. The Arduino code can be found in the [src](/src) folder. The code can be uploaded using [PlatformIO](https://docs.platformio.org/en/latest/integration/ide/vscode.html).
2. After booting up the Raspberry Pi, connect via [ssh](https://www.raspberrypi.com/documentation/computers/remote-access.html#ssh). Enable the camera with `sudo raspi-config` and the following commands. Then reboot for the changes to take effect.

    ```txt
    Interface Options  →  Legacy Camera  →  Disable (important!)
    Interface Options  →  CSI Camera     →  Enable
    ```

3. Install the following packages:

    ```bash
    sudo apt-get update
    sudo apt-get install python3-opencv python3-websockets python3-numpy python3-pyserial python3-picamera2
    ```

4. Clone the repository and run the main script:

    ```bash
    git clone https://github.com/flawil-beavers/Future-Engineers_2025.git
    ```

5. Running the robot in dev mode

    Check in the config file, if the correct usb port is set for the Arduino. Check the correct port with `ls /dev/tty*` and look for the port that is connected to the Arduino. Change the port in the config file to the correct port.

    Navigate to the `raspberry_pi` directory and run the main script:

    ```bash
    cd Future-Engineers_2025/raspberry_pi
    python3 main.py
    ```

    To launch the robot, switch the start button to the start position. The robot will now start driving autonomously. If you want to watch the live stream just open the web interface in your browser and click the connect button. To pause and resume the robot, you can press the stop button on the robot. By pressing `ctrl+c` multiple times in the ssh session you can stop the robot.

6. Next steps

    - To make the program executable run the following commands in the `raspberry_pi` folder:

        ```bash
        chmod +x main.py
        ```

        Now you can start the robot using `./main.py` when in the `raspberry_pi` folder.

    - Run [`setup_ssh.bat`](other/setup_ssh.bat) to configure your device to connect to the Raspberry Pi via ssh without password.
    - Try out the different flags:

        ```bash
        python3 main.py --headless  # Run in headless mode without web interface
        python3 main.py --pillars   # Run in pillar mode
        python3 main.py --shutdown  # Shutdown after run
        python3 main.py --calibrate # Disable driving and moving to next states
        python3 main.py --skip-arduino # Skip Arduino connection
        ```

## Future Improvements

**Mechanical Improvements**

- Build a robot capable of steering tighter curves, enabling easier parallel parking.
- Redesign the connection between the back and front steering axes to reduce slack.
- Consider using fully 3D-printed parts for the steering assembly to further minimize play.
- Incorporate bearings to drive and steer the axles more smoothly.
- Remake the custom metal steering rod to ensure proper alignment, so front and back axles steer equally. In our current version they aren't aligned properly.

**Electronics & Sensors**

- Use a more advanced gyro that integrates angular acceleration automatically. E.g. [BNO085](https://www.adafruit.com/product/4754)
- Develop a custom PCB for all electronics to simplify assembly; current components fit well but a PCB would streamline the setup and reduce errors due to dry solder joints
- Include a BMU to monitor the battery voltage, alert the user when it needs replacing, and safely shut down the robot. Currently, we have to change the battery every hour to prevent deep discharge.

**Software Improvements**

- Increase the main loop speed, potentially switching to C++, to improve overall responsiveness.
- Adjust PD controllers to account for variable loop times, ensuring the derivative term reflects actual time intervals.
- Improve color filtering to handle challenging lighting conditions, such as warm indoor light, outdoor reflections, or poorly lit pillars. This caused some problems while training in our cellar.

<!-- $env:MERMAID_BIN="C:\Users\philk\AppData\Roaming\npm\mmdc.cmd"
pandoc README.md -o README.pdf --pdf-engine=xelatex -V mainfont="Segoe UI Emoji" --filter pandoc-mermaid -->

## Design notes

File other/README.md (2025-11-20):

# other/

This folder contains the following files:

- `setup_ssh.bat` The ssh setup script for windows devices that adds the robot's secret key to the known hosts. This simplifies future connections so that the user does not have to type the password again.
- `stream.html` The html file for the stream viewer. Open it in the default browser to connect to the robot stream.
- `upload.sh` Script to upload the program files to the robot. For apple devices.
- `gyro/` This folder contains gyro calibration data sets and a Python script to visualize them.

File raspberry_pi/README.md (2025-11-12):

# raspberry_pi/

This folder contains the following files:

- `car.service` This file contains the automatic startup service for the robot program on Raspberry Pi devices.
- `config.json` The configuration file for the robot program in JSON format.
- `config.py` This file reads the config.json file.
- `helpers.py` This file contains helper functions for the robot program.
- `pipeline.py` This file contains the image processing pipeline for the robot program.
- `main.py` This is the current main file.
- `rounddir.py` This file contains functions to handle round direction detection.
- `setup_autorun.sh` Script to set up the robot program to run automatically on startup.
- `setup_networking.sh` Script to set up the networking for the robot.
- `tests/` This folder contains some scripts to test the robot.

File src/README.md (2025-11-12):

# src/

This folder contains the following files:

- `main.cpp` The main file for PlatformIO for the arduino nano.

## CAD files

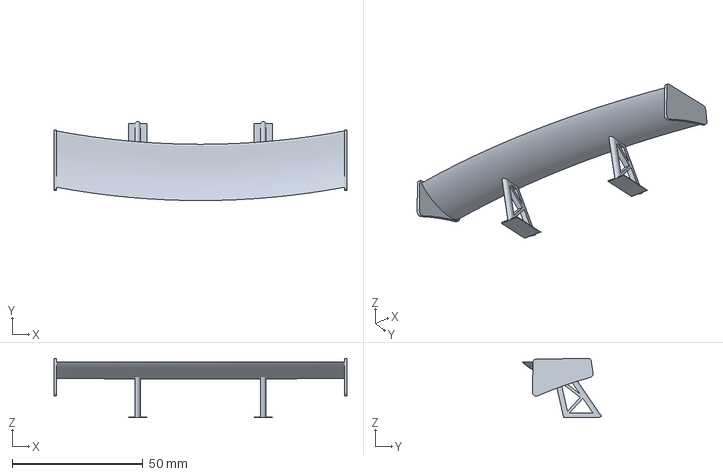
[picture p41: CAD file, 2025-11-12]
CAD/Seperate Parts/spoiler_full_2.3mf
112.0 x 30.3 x 22.7 mm

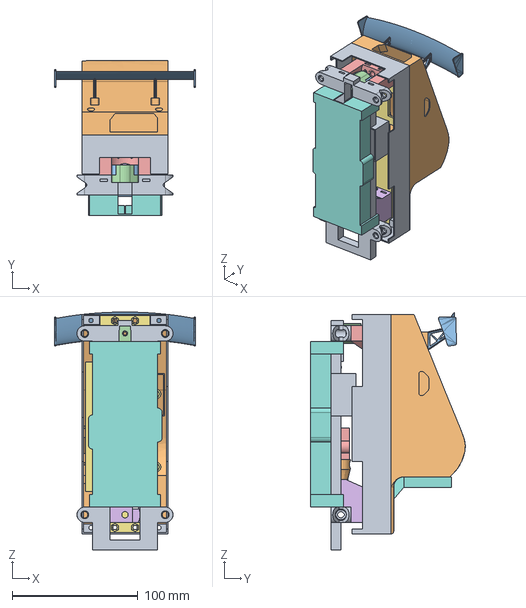
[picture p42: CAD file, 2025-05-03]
CAD/Car v87.step
112.0 x 122.9 x 189.0 mm

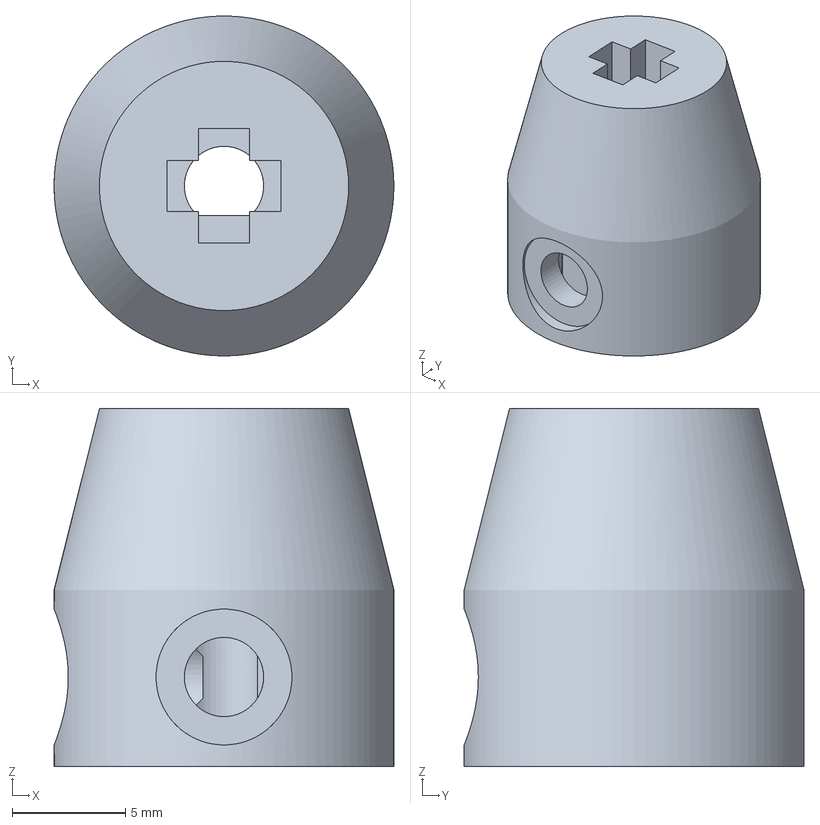
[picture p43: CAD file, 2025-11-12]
CAD/Seperate Parts/Shaft.3mf
15.0 x 15.0 x 15.8 mm

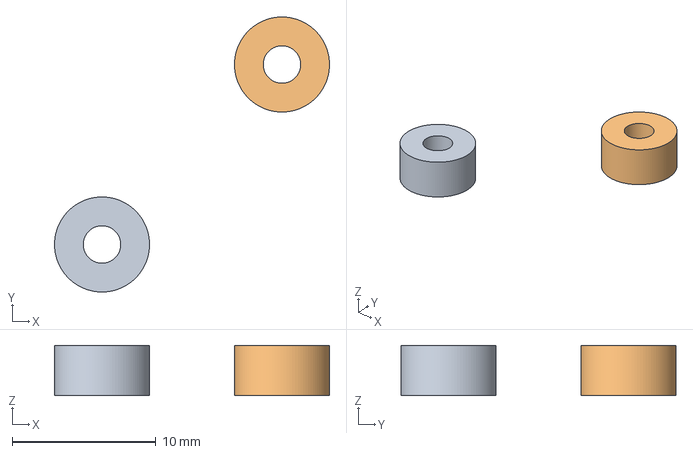
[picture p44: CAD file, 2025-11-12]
CAD/Seperate Parts/Motor driver spacer top.3mf
19.1 x 19.1 x 3.50 mm
Motor driver spacer top x 2

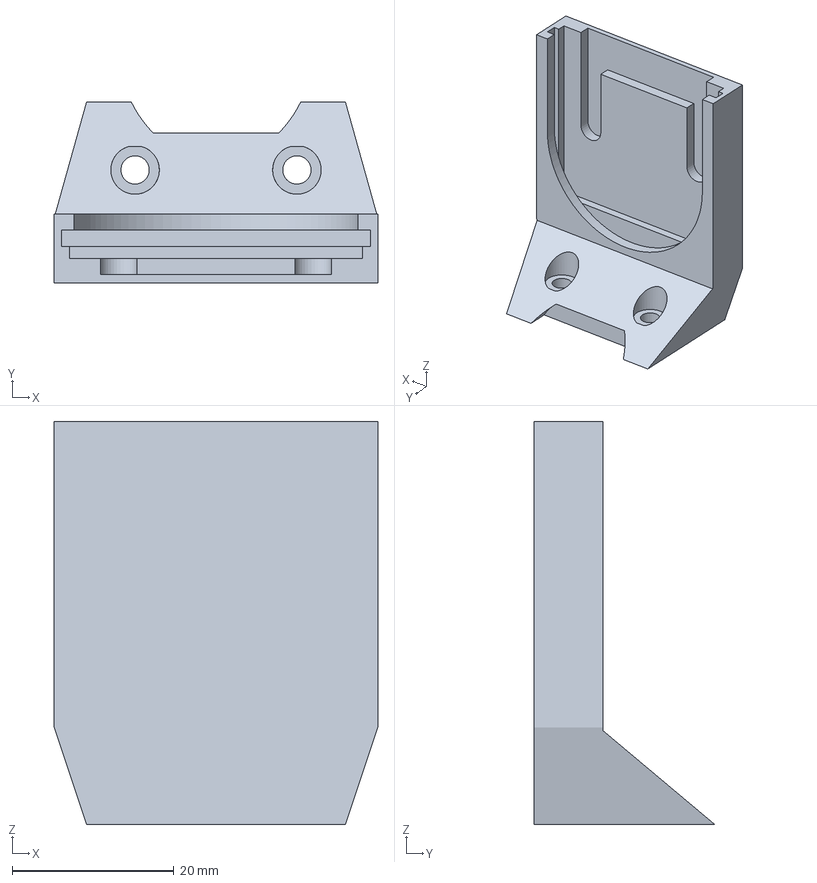
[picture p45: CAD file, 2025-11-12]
CAD/Seperate Parts/Camera mount.3mf
40.0 x 22.3 x 49.8 mm

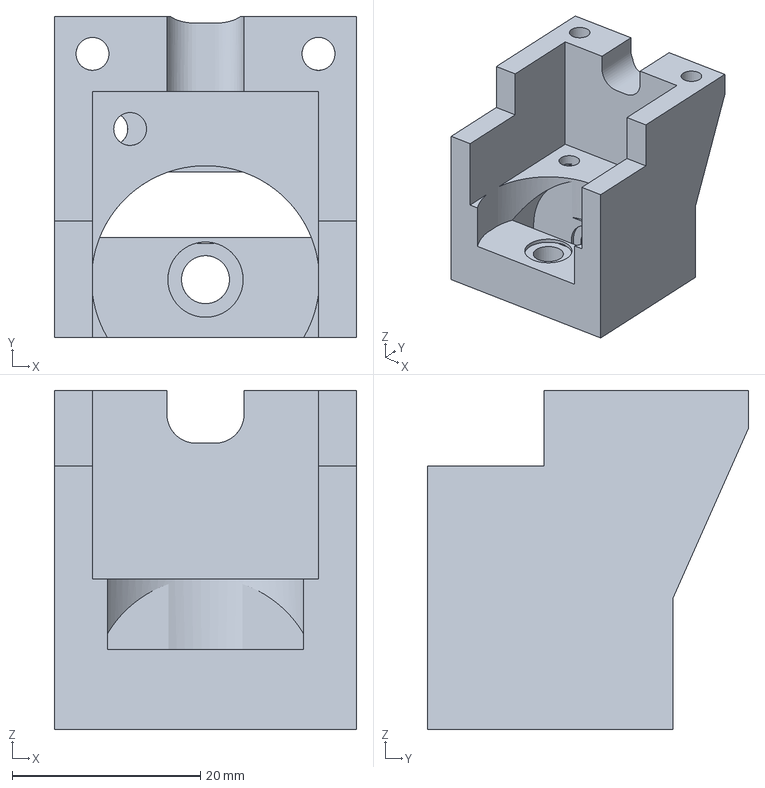
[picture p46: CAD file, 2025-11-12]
CAD/Seperate Parts/Gerbox front.3mf
32.1 x 34.1 x 36.0 mm

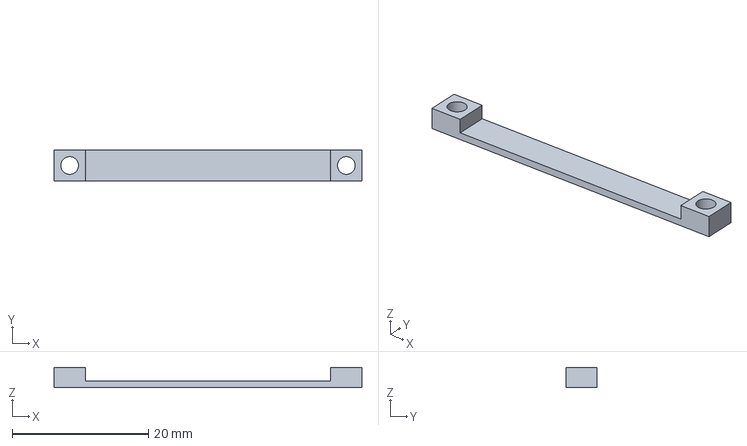
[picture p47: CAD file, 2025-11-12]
CAD/Seperate Parts/Motor driver spacer.3mf
45.2 x 4.60 x 3.00 mm

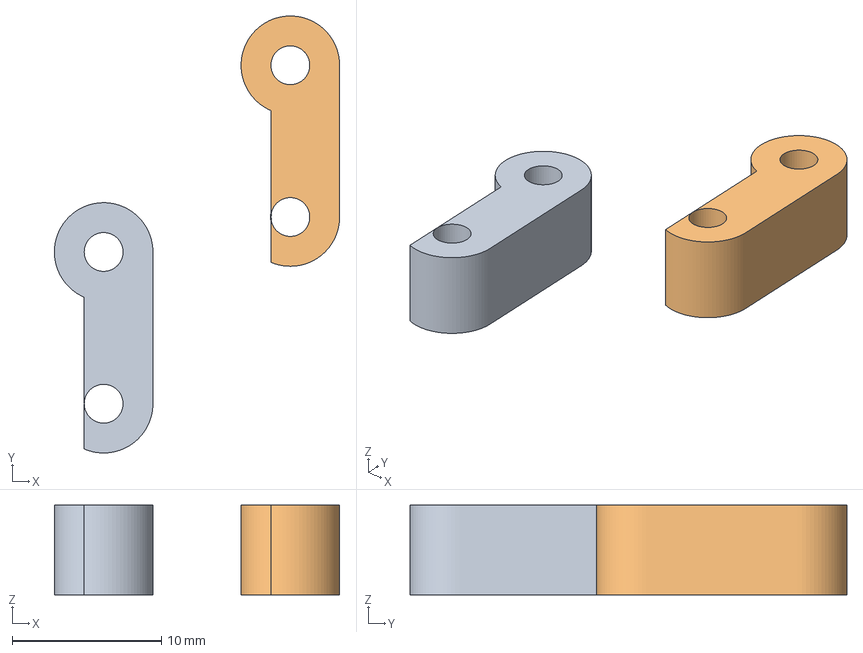
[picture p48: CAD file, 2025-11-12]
CAD/Seperate Parts/Voltager regulator spacer top.3mf
19.1 x 29.3 x 6.00 mm
Voltager regulator spacer top x 2

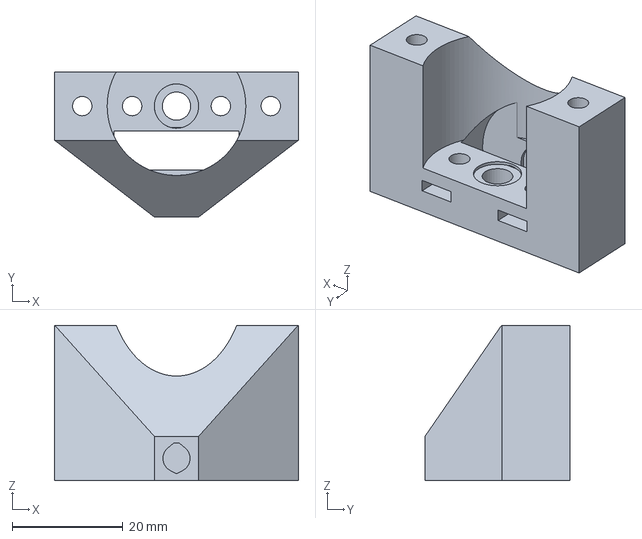
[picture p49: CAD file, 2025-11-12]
CAD/Seperate Parts/Gearbox back.3mf
44.0 x 26.1 x 28.0 mm

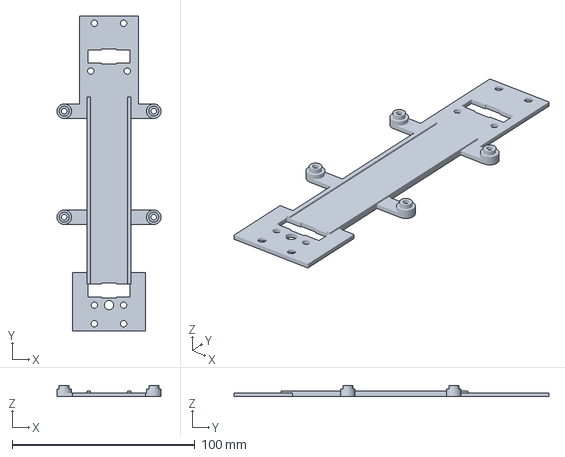
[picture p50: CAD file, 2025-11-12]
CAD/Seperate Parts/Rasbperry holder.3mf
57.0 x 172.3 x 6.00 mm

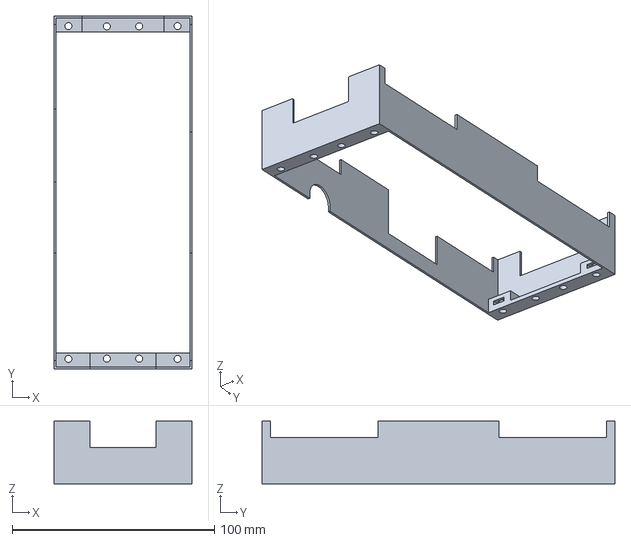
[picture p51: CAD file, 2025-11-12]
CAD/Seperate Parts/Cover top lower.3mf
68.0 x 174.5 x 31.0 mm

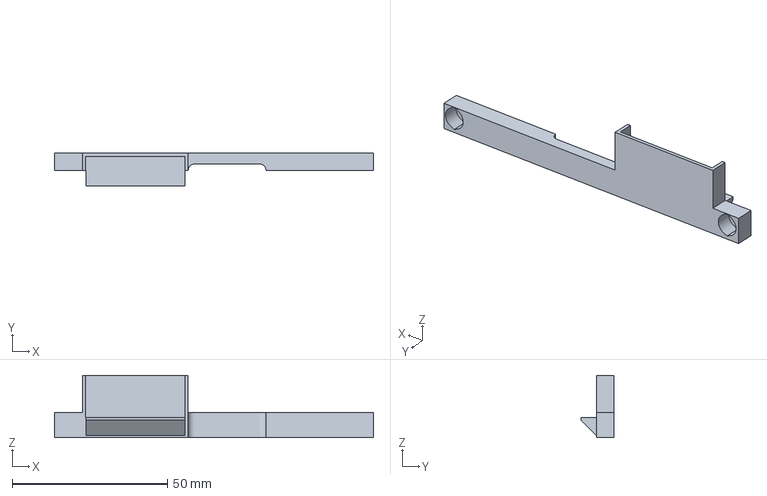
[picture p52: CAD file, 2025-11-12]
CAD/Seperate Parts/Battery holder.3mf
102.6 x 10.5 x 20.0 mm

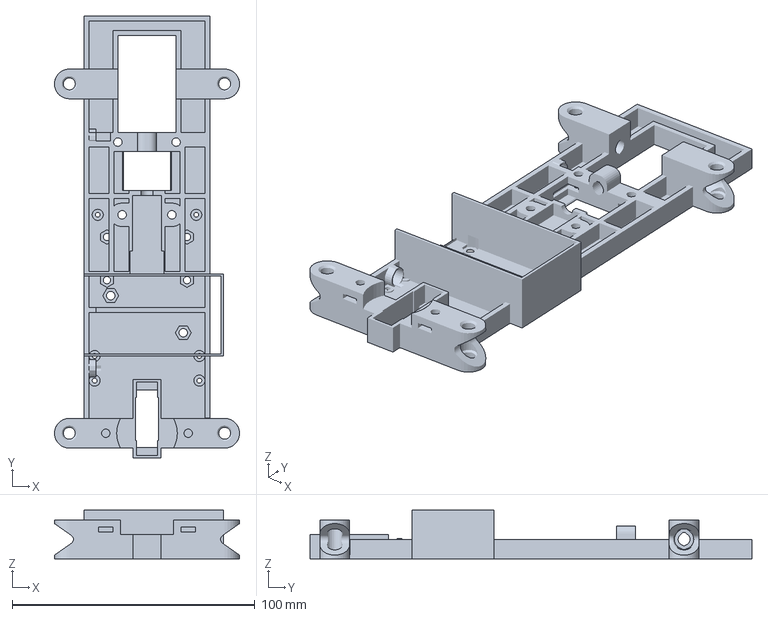
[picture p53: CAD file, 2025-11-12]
CAD/Seperate Parts/Base.3mf
76.3 x 182.2 x 20.0 mm

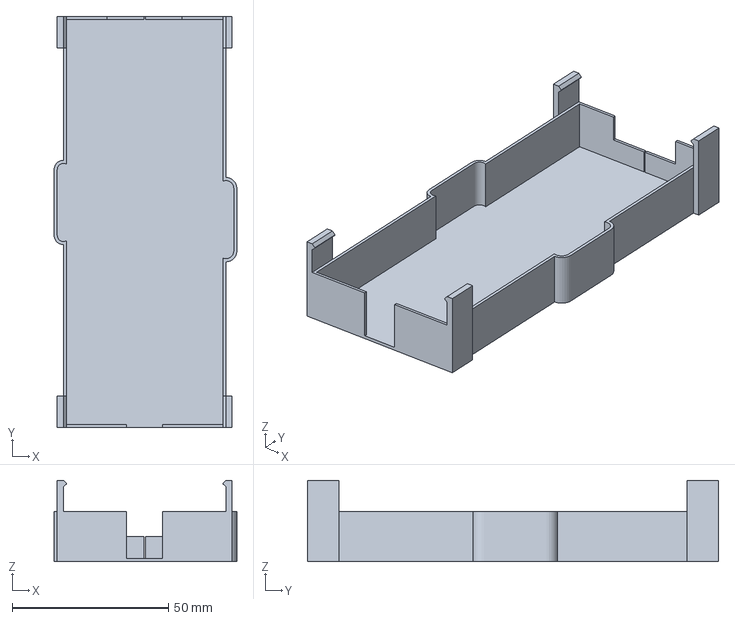
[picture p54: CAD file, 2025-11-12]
CAD/Seperate Parts/Bottom cover.3mf
58.5 x 131.5 x 26.0 mm

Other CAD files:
CAD/Seperate Parts/Servo shaft lego.3mf
CAD/Seperate Parts/Cover top upper.3mf
CAD/Seperate Parts/DC motor cover.3mf
CAD/Seperate Parts/Gearbox front inset.3mf
CAD/Seperate Parts/Gyro spacer.3mf
CAD/Seperate Parts/Servo shaft.3mf

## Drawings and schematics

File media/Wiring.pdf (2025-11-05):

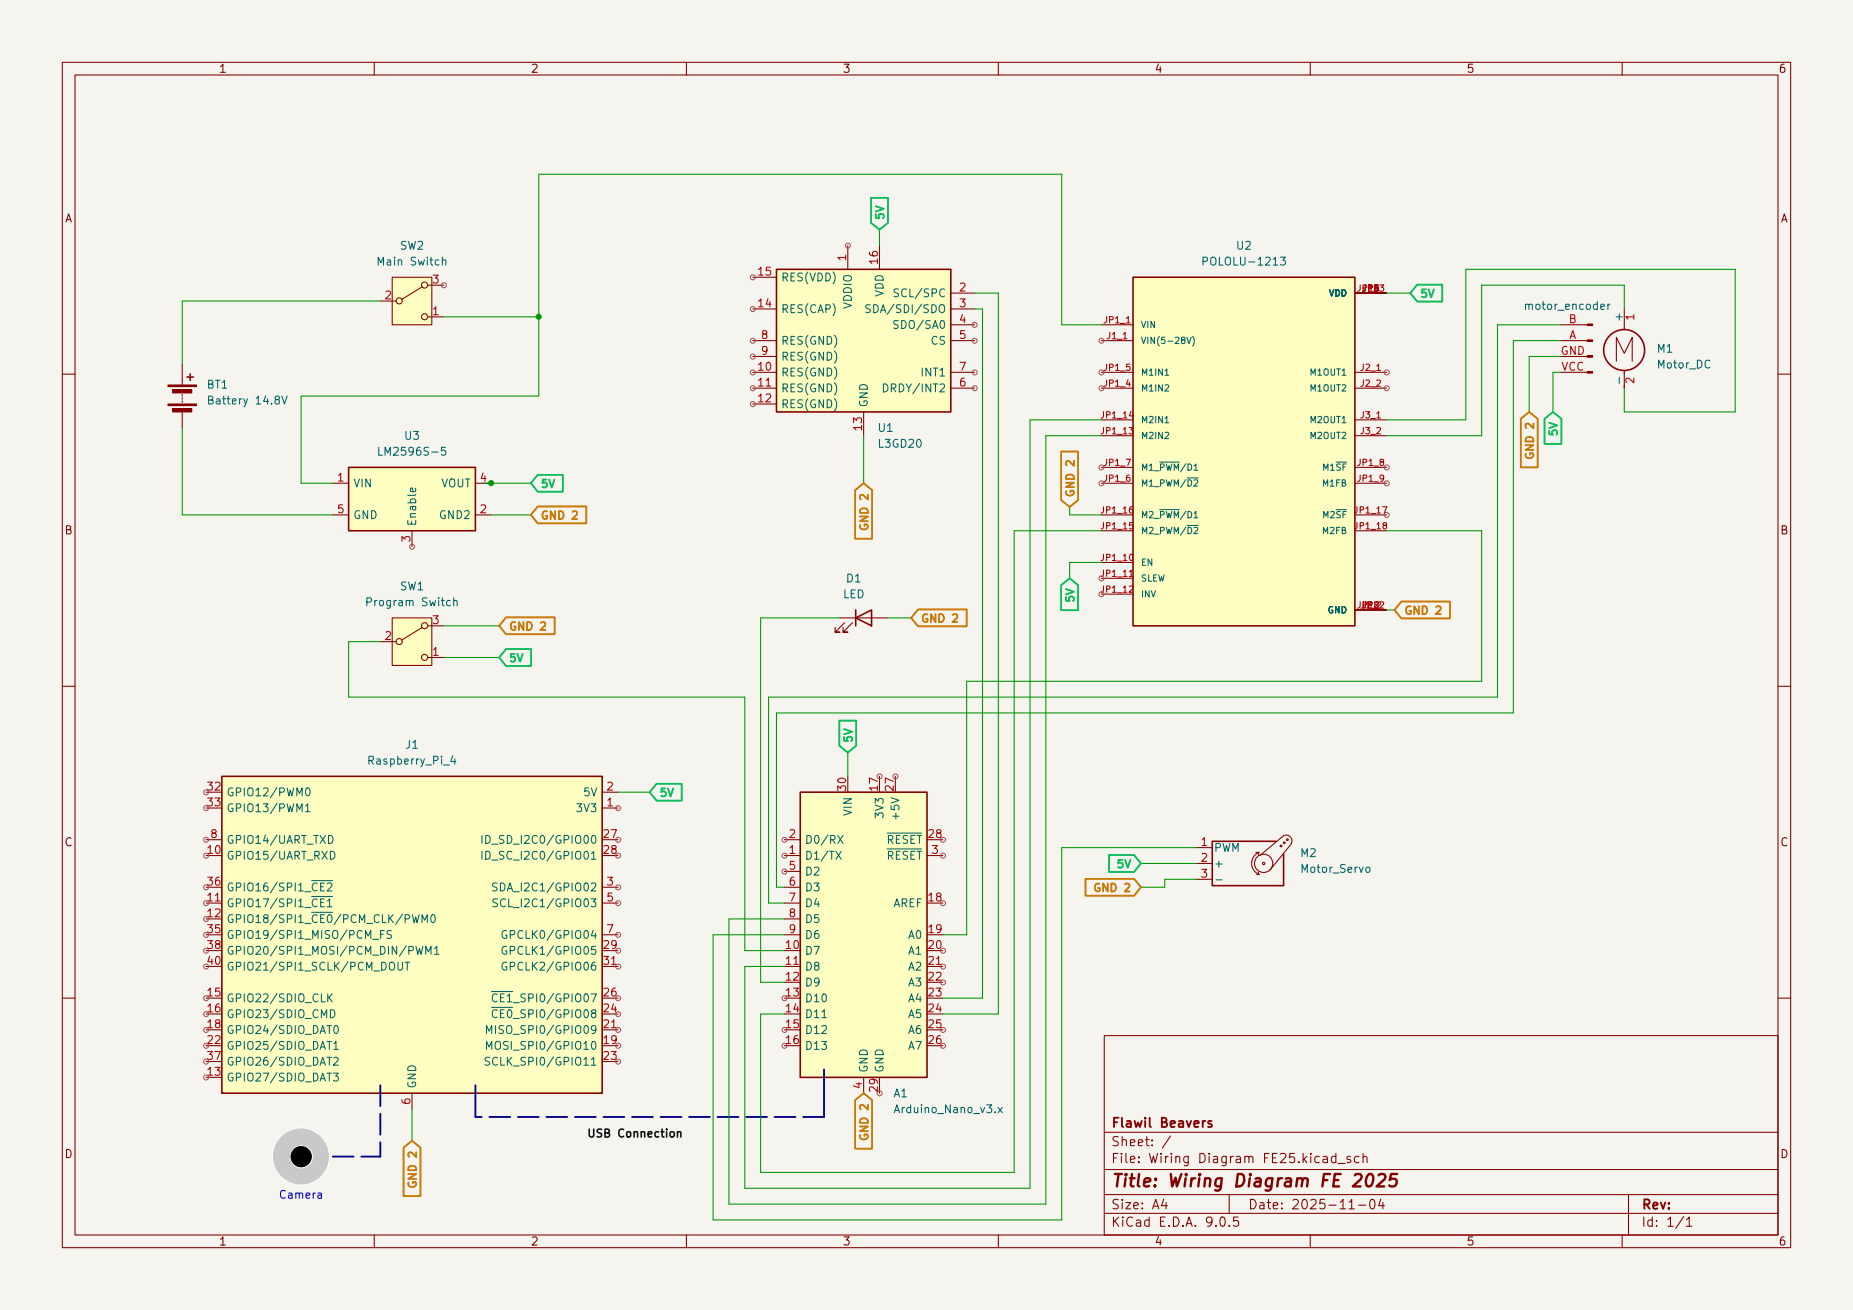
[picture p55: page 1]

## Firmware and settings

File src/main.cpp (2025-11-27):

#include <Arduino.h>
#include <Servo.h>
#include <PinChangeInterrupt.h>
#include <Adafruit_Sensor.h>
#include <Adafruit_L3GD20_U.h>
#include <Wire.h>

Servo servo;

// pin definitions
const int servoPin = 6;
const int enaPin = 11;
const int in1Pin = 5;
const int in2Pin = 8;

const int enTogglePin = 7;

const int encoderPinA = 3;
const int encoderPinB = 4;

const int currentPin = 14; // current sensor pin of motor driver

const int ledPin = 9;

// ------ drive settings ------
// encoder settings
const int gear_ratio = 150.58;                                     // gear ratio of the motor
const int countperrev = gear_ratio * 12;                           // counts per revolution of the motor
const float counter_to_mm = 20.0 / 28.0 * PI * 62.4 / countperrev; // mm per encoder count

long encoder_pos = 0;
int encoder_dir = 1; // 1 -> CCW, -1 -> CW

bool en_state = false; // enable state
const char en_state_true[] = "enable start";
const char en_state_false[] = "enable stop";

// dc motor settings
const int max_dc = 200;        // max duty cycle for motor driver
const int min_dc = 0.25 * 255; // min duty cycle for motor driver
const float max_acc_dc = 255;  // max acceleration duty cycle for motor driver (dc/s)
float current_dc = 0;          // current duty cycle for motor driver
float acc = 700;               // acceleration speed (mm/s^2)
bool disable_dc = false;       // enable dc motor
bool hold_dc = false;

// current sensor settings
const float dc_to_current = 5.0 / 1024 * 0.525; // conversion factor from duty cycle to current (A)
const float max_current = 0.5;   // max current (A)

// speed settings
float current_speed = 0;
int target_speed = 0; // target speed for the motor in mm/s
unsigned long acc_time = 20;
unsigned long last_acc_time = 0;

float last_speed = 0;

// steering settings
const int middle = 97; // +55 -55
const int degree_max = middle + 30;
const int degree_min = middle - 30;
int current_degree = 0;
int set_degree = 0;
bool disable_servo = false;
int last_angle = 0;

// manual stalling detection
long stall_encoder_pos = 0; // current encoder position

// PID
float target_distance = 0; // target encoder position in mm

float measured_speed = 0;   // measured speed in mm/s
float current_distance = 0; // current distance in mm
float last_distance = 0;    // last distance in mm
float Kp = 4.0;             // proportional gain for PID controller
float Ki = 3.0;             // integral gain for PID controller
float Kd = 1.0;             // derivative gain for PID controller
float i_max = 150.0;        // max integral value for PID controller
float pid_integral = 0.0;   // integral term for PID controller
float last_error = 0.0;     // last error for PID controller

// time variables
unsigned long current_time = 0;
unsigned long last_time = 0;
unsigned long last_status_time = 0;           // when the last status was printed
unsigned long last_loop_time_us = 0;          // last loop time in microseconds
float last_loop_time = 0;                     // last loop time in seconds
unsigned long last_enable_interrupt_time = 0; // last time the enable interrupt was called
unsigned long last_steering_command = 0;
unsigned long steering_diff = 0;

sensors_event_t event;
float degree = 0;
float degree_calibrated = 0;
float offset = 0;
float last_offset = 0;
float offset_calibrated = 0;
float last_offset_calibrated = 0;
// float y = -0.0006x - 0.0034
const float offset_m = -0.0006;
const float offset_b = -0.0034;

unsigned long last_offset_time = 0;
const float scaling_calibrated = 1800 / 1750.03; // deg measured for 5 rotations

int temperature = 0;
float temperature_average = 0; // average temperature since last offset time

// initialise gyro
Adafruit_L3GD20_Unified gyro;

#define BUFFER_SIZE 64

char ringBuffer[BUFFER_SIZE];
int head = 0;
int tail = 0;

// debug variables
int dc_out = 0;
float pid_before_checking = 0;

/*
Set the steering angle of the servo
*/
void steer(int angle)
{
  if (angle == last_angle) // to remove unnecessary writes
  {
    return;
  }
  if (disable_servo)
  {
    return;
  }
  angle = angle + middle;
  if (angle > degree_max)
  {
    angle = degree_max;
  }
  else if (angle < degree_min)
  {
    angle = degree_min;
  }
  servo.write(angle);
  last_angle = angle;
}

/*
Function to set the steering angle of the servo
*/
void set_steering(int angle)
{
  // disable_servo = false;
  set_degree = angle;
}

/*
Set the duty cycle of the motor driver.
The duty cycle is limited by max_dc, min_dc and max_acc_dc.
dc can be a positive or negative value.
*/
void set_dc(float dc)
{
  if (disable_dc || fabs(dc) < min_dc)
  {
    digitalWrite(in1Pin, LOW);
    digitalWrite(in2Pin, LOW);
    current_dc = dc;
    return;
  }
  if (dc != 0 && fabs(dc) > max_dc)
  {
    dc = max_dc * (dc / fabs(dc));
  }
  if (dc > current_dc + max_acc_dc * last_loop_time)
  {
    dc = current_dc + max_acc_dc * last_loop_time;
  }
  else if (dc < current_dc - max_acc_dc * last_loop_time)
  {
    dc = current_dc - max_acc_dc * last_loop_time;
  }
  dc_out = fabs(dc);
  analogWrite(enaPin, dc_out);
  if (dc > 0)
  {
    digitalWrite(in1Pin, LOW);
    digitalWrite(in2Pin, HIGH);
  }
  else if (dc < 0)
  {
    digitalWrite(in1Pin, HIGH);
    digitalWrite(in2Pin, LOW);
  }
  current_dc = dc;
}

/*
Calculate distance from encoder position
*/
float get_distance(long encoder_pos)
{
  return encoder_pos * counter_to_mm;
}

/*
Estimates dc for a given value in mm/s
50 dc = 300 mm/s
Not very accurate yet as just one measurement is used from the past loop
*/
int estimate_dc(float speed)
{
  float distance = get_distance(encoder_pos);
  float dc = speed / distance * max_dc; // todo: check if this is correct
  if (dc > max_dc)
  {
    dc = max_dc;
  }
  else if (dc < min_dc)
  {
    dc = min_dc;
  }
  return dc;
}

/*
PID controlled speed function
*/
void pid_speed()
{
  if (last_loop_time == 0)
  {
    return;
  }
  float error = target_distance - current_distance;
  pid_integral += error * last_loop_time;
  pid_before_checking = pid_integral;
  if (pid_integral != 0 && fabs(pid_integral) > i_max)
  {
    pid_integral = i_max * (pid_integral / fabs(pid_integral));
  }
  float speed = Kp * error + Ki * pid_integral + Kd * (error - last_error) / last_loop_time;
  set_dc(speed);
  last_error = error;
}

/*
Loop function that runs each time the loop is called
This function takes care of acceleration
*/
void drive_loop()
{
  if (last_loop_time == 0) // don't do loop if not yet initialised; so we don't divide by 0
  {
    return;
  }
  steer(set_degree);
  if (!hold_dc)
  {
    if (fabs(target_speed - current_speed) > 1)
    {
      current_speed += (target_speed - current_speed) / fabs(target_speed - current_speed) * acc * last_loop_time;
    }
    else
    {
      current_speed = target_speed;
    }
    if (!disable_dc)
    {
      target_distance += current_speed * last_loop_time;
    }
  }
  else if (disable_dc)
  {
    return;
  }
  pid_speed();
  // measured_speed = (current_distance - last_distance) / last_loop_time; // approximate speed in mm/s todo: average over multiple loops
}

/*
Function to set the acceleration speed
*/
void set_acceleration(int acceleration)
{
  if (acceleration < 0)
  {
    acceleration = 0;
  }
  acc = acceleration;
}

/*
Stops both motors
*/
void stop(bool hold = false) // todo rework emergency stop
{
  last_speed = current_speed;
  if (!hold)
  {
    disable_dc = true;
    pid_integral = 0;
    last_error = 0;
    hold_dc = false;
  }
  else
  {
    disable_dc = false;
    hold_dc = true;
  }

  disable_servo = true;
}

/*
Function to set the speed

If no speed is given, the last speed is used before the robot was paused
*/
void set_speed(int speed = last_speed) // todo when setting speed to zero no emergency stop should be called
{
  // disable_dc = false;
  // disable_servo = false;
  digitalWrite(ledPin, LOW);
  hold_dc = false;
  target_speed = speed;
  last_speed = speed;
}

/*
Get the temperature from the gyro, used mainly for temperature compensation
*/
int get_temperature()
{
  Wire.beginTransmission(L3GD20_ADDRESS);
  Wire.write(GYRO_REGISTER_OUT_TEMP); // Set read bit
  Wire.endTransmission(false);        // Send repeated start
  Wire.requestFrom(L3GD20_ADDRESS, 1);

  if (Wire.available())
  {
    temperature = (int8_t)Wire.read(); // Read as signed 8-bit integer
  }
  return temperature;
}

void gyro_config(float time_interval = 10)
{
  if (current_time - last_offset_time > time_interval * 1000000)
  {
    last_offset_time = current_time;
    offset = degree - last_offset;
    offset_calibrated = degree_calibrated - last_offset_calibrated;
    Serial.print(offset / time_interval, 6);
    Serial.print(", ");
    Serial.print(temperature_average / time_interval, 6);
    Serial.print(", ");
    Serial.println((degree_calibrated - last_offset_calibrated) / time_interval, 6);
    temperature_average = 0;
    last_offset += offset;
    last_offset_calibrated += offset_calibrated;
  }
}

void pid_config_print()
{
  if (current_time - last_status_time > 200000)
  {
    last_status_time = current_time;
    // Serial.print("time passed (ms): ");
    // Serial.print(last_loop_time * 1000);
    // Serial.print(" encoder_pos: ");
    // Serial.print(get_distance(encoder_pos));
    Serial.print(" target_speed: ");
    Serial.print(target_speed);
    Serial.print(" current_speed: ");
    Serial.print(current_speed);
    // Serial.print(" target_distance: ");
    // Serial.print(target_distance);
    // Serial.print(" measured_speed: ");
    // Serial.print(measured_speed);
    Serial.print(" current_dc: ");
    Serial.print(current_dc);
    Serial.print(" kp: ");
    Serial.print(Kp);
    Serial.print(" ki: ");
    Serial.print(Ki);
    Serial.print(" kd: ");
    Serial.print(Kd);
    Serial.print(" dc: ");
    Serial.print(current_dc);
    Serial.print(" error: ");
    Serial.print(target_distance - current_distance);
    Serial.print(" pid_integral: ");
    Serial.print(pid_integral);
    Serial.print(" dc_out: ");
    Serial.print(dc_out);
    Serial.print(" pid_before_checking: ");
    Serial.print(pid_before_checking);
    Serial.print("\r\n");
  }
}

void gyro_config_print()
{
  if (current_time - last_status_time > 200000)
  {
    last_status_time = current_time;
    Serial.print("time passed (ms): ");
    Serial.print(last_loop_time * 1000);
    Serial.print(" temperature: ");
    Serial.print(get_temperature());
    Serial.print(" degree: ");
    Serial.print(degree * 180 / PI);
    Serial.print(" degree_calibrated: ");
    Serial.print(degree_calibrated * 180 / PI);
    Serial.print("\r\n");
  }
}

int last_current_time_int = 0;
int last_value_2 = 0;
int time_now_int = 0;

void parseMessage(char *msg)
{
  char cmd[3]; // To store the 2-char command
  int value = 0;

  sscanf(msg, "%1s", cmd);

  // skip whitespace
  char *beg = ++msg;

  while (*beg == ' ')
  {
    beg++;
  }

  char *second_int = beg;

  while ((*second_int >= '0' && *second_int <= '9') || *second_int == '-')
  {
    second_int++;
  }
  value = atoi(beg);
  int value_2 = atoi(++second_int);
  // Serial.println("ok");
  switch (cmd[0])
  {
  case 'd':
    set_speed(value);
    break;
  case 's':
    set_steering(value);
    break;
  case 'n':
    Serial.println(get_distance(encoder_pos));
    break;
  case 'p':
    stop();
    current_speed = 0;
    target_distance = current_distance;
    break;
  case 'h':
    stop(true);
    break;
  case 'q':
    Kp = value / 10.;
    break;
  case 'w':
    Ki = value / 100.;
    break;
  case 'e':
    Kd = value / 10.;
    break;
  case 'g':
    Serial.println(degree_calibrated * 180 / PI);
    break;
  case 't':
    Serial.println(get_temperature());
    break;
  case 'a':
    set_acceleration(value);
    break;
  case 'r':
    set_speed();
    break;
  case 'o':
    digitalWrite(ledPin, HIGH);
    break;
  case 'f':
    digitalWrite(ledPin, LOW);
    break;
  case 'z':
    Serial.print(get_distance(encoder_pos));
    Serial.print(",");
    Serial.println(degree_calibrated * 180 / PI);
    break;
  case 'y':
    set_speed(value);
    set_steering(value_2);
    Serial.print(get_distance(encoder_pos));
    Serial.print(",");
    Serial.println(degree_calibrated * 180 / PI);
    break;
  case 'x':
    Serial.print("Steering diff: ");
    Serial.print(steering_diff);
    Serial.println(" us");
    break;
  case 'm':
    disable_dc = false;
    disable_servo = false;
    set_speed();
    break;
  }
}

void processMessage()
{
  // Message extraction from ring buffer
  char message[BUFFER_SIZE];
  int index = 0;
  while (tail != head)
  {
    char currentChar = ringBuffer[tail];
    tail = (tail + 1) % BUFFER_SIZE;

    if (currentChar == '\n')
    { // End of message
      break;
    }

    message[index++] = currentChar;
  }

  message[index] = '\0'; // Null-terminate the message string

  // Parse the extracted message
  parseMessage(message);
}

void check_serial_available()
{
  while (Serial.available() > 0)
  {
    char c = Serial.read();
    ringBuffer[head] = c;
    head = (head + 1) % BUFFER_SIZE;

    if (head == tail)
    {
      // Buffer overflow, discard the oldest character
      tail = (tail + 1) % BUFFER_SIZE;
    }
    if (c == '\n')
    {
      processMessage();
    }
  }
}

void check_current()
{ // probably won't work as the current is too low
  int dc = analogRead(currentPin);
  float current = float(dc) * dc_to_current; // convert to current in A
  // Serial.print("Current: ");
  // Serial.println(current, 6);
  if (current > max_current)
  {
    stop();
    Serial.println("Current limit exceeded, stopping robot");
    // delay(1000);
  }
}

void check_stalling()
{
  if (fabs(stall_encoder_pos - encoder_pos) < 4 && fabs(current_dc) > max_dc * 0.9 && !disable_dc)
  {
    Serial.print("Stall detected, stopping robot: diff_distance:");
    Serial.print(fabs(stall_encoder_pos - encoder_pos));
    Serial.print(", current_dc");
    Serial.println(current_dc);
    // disable motor
    stop();
    current_speed = 0;
    target_distance = current_distance;
  }
  stall_encoder_pos = encoder_pos; // update stall position
}

/*
Change enable state based on interrupt
This is the start stop and pause button

Switch on:
Starts the robot
When the robot is paused this makes the robot resume

Switch off:
Pauses the robot
*/
void enable_interrupt()
{
  if (current_time - last_enable_interrupt_time < 100000)
  {
    return;
  }
  last_enable_interrupt_time = current_time;
  en_state = !en_state;
  if (en_state)
  {
    disable_dc = false;
    disable_servo = false;
    set_speed();
    digitalWrite(ledPin, LOW);
    Serial.println(en_state_true);
  }
  else
  {
    stop();
    digitalWrite(ledPin, HIGH);
    Serial.println(en_state_false);
  }
}

/*
Update gyro degree, has to be called each loop, so that integration works reliably
*/
void update_gyro()
{
  gyro.getEvent(&event);
  degree += event.gyro.z * last_loop_time;
  int temperature = get_temperature();
  if (temperature < 0)
  {
    degree_calibrated += (event.gyro.z - (-0.0007 * temperature + -0.0108)) * last_loop_time * 0.98 * scaling_calibrated; // / 2 experimentally included
  }
  else
  {
    degree_calibrated += (event.gyro.z - (offset_m * temperature + offset_b)) * last_loop_time * scaling_calibrated; // / 2 experimentally included
  }

  temperature_average += temperature * last_loop_time;
}

void loop_updater()
{
  last_time = current_time;
  last_distance = current_distance;

  current_time = micros();
  last_loop_time_us = current_time - last_time;
  last_loop_time = last_loop_time_us / 1000000.0; // in seconds

  current_distance = get_distance(encoder_pos);

  update_gyro();
}

void update_encoder(int encoderPin)
{
  int a = digitalRead(encoderPinA);
  int b = digitalRead(encoderPinB);
  if ((a == b && encoderPin == encoderPinA) || (a != b && encoderPin == encoderPinB))
  {
    encoder_dir = 1;
  }
  else
  {
    encoder_dir = -1;
  }
  encoder_pos += encoder_dir;
}

void update_encoder_a()
{
  update_encoder(encoderPinA);
}

void update_encoder_b()
{
  update_encoder(encoderPinB);
}

void setup()
{
  pinMode(in1Pin, OUTPUT);
  pinMode(in2Pin, OUTPUT);

  pinMode(enTogglePin, INPUT);

  servo.attach(servoPin);

  pinMode(encoderPinA, INPUT);
  pinMode(encoderPinB, INPUT);
  pinMode(currentPin, INPUT);
  pinMode(ledPin, OUTPUT);
  digitalWrite(ledPin, LOW);

  digitalWrite(in1Pin, LOW);
  digitalWrite(in2Pin, LOW);
  analogWrite(enaPin, 0);
  Serial.begin(115200);

  attachPinChangeInterrupt(digitalPinToPinChangeInterrupt(encoderPinA), update_encoder_a, CHANGE);
  attachPinChangeInterrupt(digitalPinToPinChangeInterrupt(encoderPinB), update_encoder_b, CHANGE);
  attachPinChangeInterrupt(digitalPinToPinChangeInterrupt(enTogglePin), enable_interrupt, CHANGE);

  en_state = digitalRead(enTogglePin) == HIGH; // initial state of the enable button

  delay(100);

  if (!gyro.begin())
  {
    /* There was a problem detecting the L3GD20 ... check your connections */
    Serial.println("Gyro error");
    while (1)
      ;
  }
  Serial.println("Gyro OK");
  gyro.enableAutoRange(true);

  for (int i = 0; i < 2; i++) // signal that the robot is ready
  {
    servo.write(middle + 1);
    delay(100);
    servo.write(middle);
    delay(100);
  }
}

void loop()
{
  loop_updater();
  check_serial_available();
  check_current();
  check_stalling();
  drive_loop();
  // pid_config_print();
  // gyro_config_print();
  // gyro_config();
}

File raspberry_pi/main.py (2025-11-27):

#!/usr/bin/env python3
import asyncio
import base64
import json
import math
import os
from time import sleep, time, perf_counter
import cv2
import numpy as np
# from datetime import datetime
# import shutil
# import subprocess
import serial
import serial.tools.list_ports
from websockets import WebSocketServerProtocol, serve
from config import ConfigLoader
from helpers import *#extract_ROI, print_past_time, Straight_Section, Lines, bound, setup_logging, Car, SharedState, find_direction, AngleBuffer, LoopTimerRegistry
from pipeline import Pipeline
from picamera2 import Picamera2
from rounddir import find_round_dir
import argparse
import libcamera
import sys
from collections import deque
import traceback

"""
raspberry_pi/main.py
---------------------
Main entrypoint for the Raspberry Pi robot. Configures camera and pipeline,
coordinates Arduino communication (gyro/odometry and motor commands), runs
the vision pipeline (color filters, ROI extraction, line detection) and
provides PD-based control primitives and a high-level state machine used
for rounds and parking maneuvers.

This module is intended to run on a Raspberry Pi with a Picamera and an
Arduino connected for motion and gyro feedback.
"""

#?: Webviewer controls for tuning colors, pd, and selecting stream

# todo: move most of this code to the main function

# turn the camera image by 180 degrees

configloader = ConfigLoader("config.json")
pipeline = Pipeline(configloader)
# Load the config file
with open("config.json", "r") as f:
    config = json.load(f)

picam2 = Picamera2()
# picam2.configure(picam2.create_preview_configuration())
preview_config = picam2.create_preview_configuration(main={"size": (640, 480)})
preview_config["transform"] = libcamera.Transform(vflip=True, hflip=True)
picam2.configure(preview_config)
picam2.start()

picam2.set_controls({
    "AwbEnable": True,
    "ScalerCrop": [
        0,
        1520,
        4065,
        1520
    ],
    # controls.AWB_TEMPERATURE: fixed_temperature
})

roi_center_w, roi_center_h = 100, 40
roi_center_x, roi_center_y = 320 - roi_center_w // 2, 200

roi_width = 100
roi_height = 150

roi_front_width = 10

current_streams = ["viz", "black", "viz"]
has_sent_streams_info = False
active_websocket = None
# Shared dictionary to hold the latest streams from cycle()

car = Car()

# Create a single shared state object
state = SharedState()

# attach an angle buffer to the shared state
state.angle_buffer = AngleBuffer(window_seconds=10.0)

# create a list with four elements of Straight_Section
straight_sections = [Straight_Section(i) for i in range(4)]

ports = serial.tools.list_ports.comports()

loop_timer = LoopTimerRegistry()

# get some frames so camera can adjust
for i in range(30):
    picam2.capture_array()

try:
    ser = serial.Serial(configloader.get_property("ArduinoSerialPort"), configloader.get_property("ArduinoBaudRate"))
except:
    print("Arduino not connected, available devices")
    ser = None
    for port, desc, hwid in sorted(ports):
        print("{}: {} [{}]".format(port, desc, hwid))

def pause_robot(resume=False):
    """Pause or resume the robot.

    Args:
        resume (bool): If True, unpause the robot; otherwise pause it.

    Toggles `car.paused` and prints a short status message. This helper is
    used by serial commands and by the main program to temporarily stop
    motion for safety or calibration.
    """
    global car
    if resume:
        car.paused = False
        print("Robot resumed")
    else:
        car.paused = True
        print("Robot paused")

async def write_serial(msg):
    """Write a message to the Arduino serial port without blocking the loop.

    The actual serial write is performed in a threadpool so the asyncio
    event loop remains responsive.

    Args:
        msg (str): Message to send (including newline if required).
    """
    loop = asyncio.get_running_loop()
    await loop.run_in_executor(None, ser.write, msg.encode())
    
async def read_serial_line():
    """Read one line from the serial port in a background thread.

    Returns the decoded, stripped line as a string.
    """
    loop = asyncio.get_running_loop()
    line = await loop.run_in_executor(None, ser.readline)
    return line.decode('utf-8').strip()

async def read_and_handle_serial_line():
    """Read a serial line and handle common control messages.

    Recognized protocol messages include:
      - "enable start" / "enable stop": toggle pause
      - Lines beginning with "Stall": mark the car as stalled
      - Lines beginning with "Error": log error

    Returns a tuple (handled: bool, line: str) where handled indicates if
    the caller-side handled the message.
    """
    line = await read_serial_line()
    if line == "enable start":
        pause_robot(True)
        return True, line
    elif line == "enable stop":
        pause_robot()
        return True, line
    elif line.startswith("Stall"):
        print(f"Stall detected: {line}")
        car.stalled = True
        return True, line
    elif line.startswith("Error"):
        print(f"Arduino error: {line}")
        return True, line
    return False, line
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

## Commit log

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2025-03-31 first version of using encoder
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2025-04-04 increase baud rate and first tests of pid speed control
2025-04-05 Refactor PID controller parameters and improve speed control logic
2025-04-07 test with pololu library; but still not working
    [main.cpp]
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2025-04-12 Refactor loop to include timing calculations and gyro data handling
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2025-04-13 add extensive temperature correction
    [main.cpp]
2025-04-14 Correct temperature correction (and divide experimentally by 2)
    [main.cpp]
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2025-04-14 fix: update in2Pin due to faulty arduino
    [main.cpp]
2025-04-15 Use forked library to override address and id of gyro
2025-04-15 Remove unused sensor libraries and clean up code
2025-04-18 Refactor main.cpp: Update gyro initialization, add temperature reading, and improve PID logging
2025-04-18 Refactor parseMessage function: Replace encoder position output with calculated distance and add calibrated degree output
    [main.cpp]
2025-04-18 Refactor main.cpp: Add steering control and enable state management, improve gyro integration
2025-04-18 Refactor roi.py: Add 'color_image' to current streams for enhanced image processing
2025-04-20 improve stop with hold and coast, improve enable button, add more states
2025-04-21 Improve gyro initialization handling: Add error detection and connection restart logic
    [main.cpp]
2025-04-25 Improve Arduino connection handling: Set timeout and enhance error messages
2025-04-25 Add SSH setup script for Raspberry Pi connection
2025-04-27 Add print_past_time function to log elapsed time and integrate it into the cycle and img_stream functions
2025-04-27 Test: Enhance robot control by integrating distance and gyro data from Arduino, and update state transition logic based on distance metrics.
2025-04-27 Refactor steering logic to prevent unnecessary servo writes and initialize last_angle. Update setup to signal robot readiness.
    [main.cpp]
2025-04-27 Refactor state machine to track angle and distance differences, update state transition logic, and enhance logging for state changes.
2025-04-28 Fix: Adjust orange lower filter value in config.json for improved color detection
2025-04-28 Style: Update main menu and color adjust width to use clamp for responsive design
2025-04-28 Enhance camera initialization: Capture initial frames for camera adjustment and update speed handling in state machine.
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2025-04-30 Refactor motor and steering settings: Update variable declarations to use const for constants and improve code clarity.
2025-04-30 Refactor color filter thresholds: Adjust red and green filter values for improved accuracy and performance. Overhaul of pillars code
2025-04-30 Adjust speed threshold and implement current sensor checks for improved motor control. Add status LED
2025-05-01 Update filter thresholds and enhance pillar tracking logic: Adjust orange filter value and modify pillar avoidance conditions based on size and y-coordinate.
2025-05-03 Add driving position calculation and update state machine for pillar avoidance
    [helpers.py]
2025-05-03 Add CAD model of whole robot
    [Car v87.step]
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2025-05-06 Refactor error calculation in cycle function with gyro smoothing; integrate bounding logic for improved error handling and update text display for distance and angle.
    [helpers.py]
2025-05-07 Refactor state machine to enhance turn state handling; update cycle function for improved correction logic based on current state
2025-05-08 Refactor state machine and cycle function to improve state transitions and error handling; update line detection logic for better corner detection and visualization.
    [helpers.py]
2025-05-09 Enhance fullscreen view with WebSocket connection button; normalize HSV calculations to percentages and round values for improved display.
2025-05-09 Refactor color filter thresholds in config.json; add inRange method in Pipeline for improved color detection and noise reduction in roi.py.
    [pipeline.py]
2025-05-09 Add logging functionality to roi.py; redirect print statements to a log file for better debugging and monitoring.
2025-05-09 Speed up communication between arduino and raspberry with "z"
2025-05-09 Refactor parking lot logic in state machine and update print statements for debugging
2025-05-09 remove overcurrent protection to make stall detection work
    [main.cpp]
2025-05-10 Adjust REDHI and ORANGELO filter values for improved detection accuracy during competition
2025-05-22 Add data files and plotting script for gyro drift analysis
2025-07-24 Update raspberry_pi/statemachine.py to raise error when wrong colour detectd
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2025-08-14 Add manual stalling detection and implement check_stalling function
    [main.cpp]
2025-08-17 Enhance websocket handling (prototype of having just one connection) and update current streams list in roi.py
2025-08-17 Add Car class to represent car state and integrate with Arduino communication
2025-08-17 Refactor Arduino communication to be asynchronous, improving handling of distance and angle data, and enhance pause functionality.
2025-08-21 Add pause functionality to Arduino communication and manage car state
2025-08-21 Refactor Arduino communication and drive/turn functions for improved clarity and performance
2025-08-21 Refactor noise reduction in filter_OB method by adjusting kernel sizes and iterations for erosion and dilation
    [pipeline.py]
2025-08-21 Refactor Arduino connection handling to be asynchronous and improve communication flow
2025-08-22 Refactor Arduino communication to improve angle handling and add delay in image streaming
2025-08-25 Update enable state messages for clarity and improve stalling detection logging
    [main.cpp]
2025-08-25 Enhance Arduino communication by adding pause functionality and improving distance and angle reporting - should improve communication time
2025-08-25 Refactor Arduino communication by removing commented-out code for clarity and maintainability
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2025-09-08 move a lot of camera processing to async functions. Make the webserver also rund more asynchronous
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2025-09-08 Update blue color filter values and adjust ROI center coordinates (reliable open challenge) but orange not working very well
2025-09-08 Fix important bug on Arduino
    [main.cpp]
2025-09-15 add stall detection to make first rounds a bit more reliable
    [helpers.py, main.cpp]
2025-09-20 First prototype of saving pillars recalibrate pillars in non-carpark sections
2025-09-22 Add skip_arduino flag to directly start Arduino without waiting for button press
2025-09-24 Refactor process_pillars and main_program for clarity and improved logic flow
2025-10-23 Add angle buffer to SharedState for improved stability in direction control update straight_angle based on straight wall following
    [helpers.py]
2025-10-27 Improve gyro resetting and using of the new angle
2025-10-27 Some direct fixes to temperatures around 50 °C that show as temperatures < 0
    [main.cpp]
2025-10-29 try to fix gyro drift by not dividing by two, add better printing
    [main.cpp]
2025-10-31 Fix temperature printing at the beginning
2025-11-01 add logs more images saved of pillars fix small bugs
    [helpers.py]
2025-11-04 add first prototype to drive into parking place by just driving to the last parking wall
2025-11-05 Fix wiring diagram format and update BOM sources
    Updated wiring diagram image format and corrected product sources in the Bill of Materials.
2025-11-05 Update Wiring Diagram image format from PDF to PNG
2025-11-05 Add Wiring diagram in PDF format and update PNG version
2025-11-05 improve parking prototype to find bottom inner corner of parking wall
2025-11-09 improve unparking by driving the correct distance from the wall
    [helpers.py, pipeline.py]
2025-11-12 add 3D files for slicer
    [Base.3mf, Battery holder.3mf, Bottom cover.3mf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]
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2025-11-12 update README with detailed assembly instructions and additional media links
2025-11-12 Adjust Obstacle Management to reflect current program logic
2025-11-12 update README with detailed assembly instructions and links to CAD files
2025-11-13 Update youtube videos change flow chart of obstacle challenge to be vertical
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2025-11-17 Add thumbnail images for various CAD parts and update README with image links
2025-11-17 Add LEGO chassis image and update README with new image reference
2025-11-17 Fix links in assembly instructions for CAD parts
2025-11-17 Update assembly instructions with thumbnail images and links for spacers
2025-11-18 rephrase sentences in mobility management and power and sense management formatting add classes
2025-11-18 add gyro calibration on robot at the beginning of the program to take the average over the last 2 s
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2025-11-20 Fix some small bugs
    [main.py, pipeline.py]
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2025-11-27 fix: correct temperature variable usage in gyro calibration
    [main.cpp]
